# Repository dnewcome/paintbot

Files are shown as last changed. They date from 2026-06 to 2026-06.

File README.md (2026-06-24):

# paintbot

Hardware for a painting robot that mirrors an operator's brush movements in real
time (a live digital twin) and replays recorded stroke performances. A raked
**vertical CoreXY easel** (3×4 ft) carrying interchangeable, force-controlled tool
heads — a **voice-coil paint brush** and a **gel extruder** — prototyped first as
standalone heads on an existing ShopBot.

## Layout
- **[`docs/`](docs/README.md)** — design docs: architecture, motion sizing, belt
  resonance, the voice-coil actuator + brush head, and the extrusion head.
- **`cad/`** — parametric [build123d](https://github.com/gumyr/build123d) parts.
  Shared dimensions live in `cad/params.py` (and `cad/params_extruder.py`); each
  part file exports an STL and self-checks watertightness.

## Building the CAD
```bash
pip install build123d trimesh
python3 cad/<part>.py        # writes build/<part>.stl and prints a sanity line
```

Status, locked decisions, and open questions are tracked in
[`docs/README.md`](docs/README.md).

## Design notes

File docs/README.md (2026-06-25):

# Paintbot — Hardware Design Docs

Physical machine that mirrors the operator's painting movements in real time
(live digital twin) and replays recorded `TwinPerformance` op streams. A raked
vertical CoreXY easel carrying a multi-stage brush head.

## Documents
- **[hardware-architecture.md](hardware-architecture.md)** — top-level concept,
  governing design drivers, work envelope, axis map & drives, subsystems.
- **[motion-sizing.md](motion-sizing.md)** — CoreXY + coarse-Z sizing: torque
  budget, stepper (open-loop, 56 V, 30T pulley) vs FOC, counterbalance.
- **[belt-resonance.md](belt-resonance.md)** — the bandwidth cap at 3×4 ft:
  belt stiffness, tension nuance, frame modes, open-loop input shaping, measuring f_n.
- **[voice-coil-actuator.md](voice-coil-actuator.md)** — custom fine-Z brush
  stroke/pressure actuator: requirements, EM design point, Path B flexure, driver.
- **[voice-coil-head.md](voice-coil-head.md)** — brush tool head built/tested on
  the existing ShopBot first: mechanical stack-up, magnetic circuit, CAD parts.
- **[voice-coil-driver.md](voice-coil-driver.md)** — single-phase current-mode
  (=force-mode) driver + nested control loop + calibration; the bench-test path.
- **[extrusion-head.md](extrusion-head.md)** — second tool head: motor-driven
  syringe pump for thick gel medium (dip-and-load, single-bore reverse-fill, fat bead).
- **[planar-corexy.md](planar-corexy.md)** — construction variant: laser/waterjet
  plates locate the motion geometry, hybridized with the 8020 frame (after corexy.com R1).
- **[coarse-z.md](coarse-z.md)** — coarse-Z stage (full machine): belt-driven MGN12
  carriage presenting a 65 mm clamp; Z is horizontal in the easel (no self-lock).
- **[bom.md](bom.md)** — consolidated bill of materials: brush head, driver, planar frame.

## Decisions locked so far
- Raked vertical CoreXY easel, **3×4 ft** work area (which dim is vertical: TBD).
- Drives: **open-loop steppers** for XY initially (56 V, high-torque NEMA23
  ≥2.5–3 N·m, low-inductance, dual-shaft, 30T 2GT pulley); upgrade path to
  closed-loop. Reserve current/force control for the voice coil.
- **Two-stage Z:** coarse belt carriage (all gross lifts) + custom voice-coil
  fine-Z (Path B flexure, ~10 mm, current = force = brush line weight).
- **Interchangeable tool heads** sharing one ShopBot/Z-plate mount: (1) voice-coil
  brush (force-controlled, live feel); (2) gel extruder (volume-metered syringe
  pump, dip-and-load, single-bore reverse-fill, ~3 mm fat-bead nozzle).
- **Y counterbalanced with constant-force / gas spring, never a counterweight.**
- Bandwidth ceiling is **belt resonance**, not motor torque → 15 mm steel-core
  belt + ≥20 mm idlers + MGN12 rails + ~50–80 N tension + input shaping.

## Top open decisions
- [ ] Bed dimension assignment: which of 3 ft / 4 ft is vertical (Y)?
- [ ] Wrist single-DOF axis: lean vs. azimuth/roll.
- [ ] Voice coil detailed design (magnetic circuit + flexure) → build123d parts.

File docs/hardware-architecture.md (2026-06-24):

# Paintbot — Hardware Architecture

Physical realization of the paintbot software twin: a robot that mirrors the
operator's painting movements in real time (live digital twin) and can replay
recorded `TwinPerformance` op streams.

## Top-level concept

A **raked vertical CoreXY easel** carrying a multi-stage brush head. The operator
moves; the machine follows with minimal perceived lag, holding (for now) a paint
brush. Drives are robotics-grade BLDC servos under field-oriented control so the
head can be torque/impedance-controlled, not just position-commanded.

## Governing design drivers

1. **Latency is dominated by sensing/compute, not mechanics.** A well-tuned
   CoreXY tracks commands within single-digit ms. The mechanical goal is "don't
   be the bottleneck"; responsiveness is won with a predictive filter that
   extrapolates operator motion to mask camera latency.
   - Budget: **<50 ms end-to-end feels responsive, <20 ms feels truly live.**
2. **Moving mass vs. acceleration is the master tradeoff.** `a = F/m`. Every
   gram on the gantry (coarse Z, voice coil, wrist, brush) costs acceleration,
   and acceleration — not top speed — is what makes mirroring feel tight.
3. **Belt + frame stiffness set the control bandwidth.** The lowest mechanical
   resonance caps how aggressively the servo loop can be tuned. At ~1.2 m belt
   spans this is a real limit; favor wide steel-core belt, high tension, short
   free spans.

## Work envelope & orientation

| Parameter | Value |
|---|---|
| Canvas / bed | **3 × 4 ft** (~914 × 1219 mm) work area |
| Orientation | Vertical easel, **raked back ~10–20°** from plumb |
| X axis | Horizontal across canvas |
| Y axis | Vertical (gravity axis — counterbalanced) |
| Z coarse | Horizontal, brush standoff / relief depth |
| Z fine (voice coil)  | Horizontal, brush stroke + pressure |
| Wrist | 1 DOF (axis TBD — lean vs. azimuth/roll) |

### Why the rake
- Slight gravity bias holds brush toward canvas.
- Paint runs *down* the canvas, not *off* it.
- More stable base against the gantry's tipping moment.

## Axis map & drives

Platform: **moteus / ODrive-class BLDC under FOC**, daisy-chained on **CAN-FD**,
single real-time host (**Raspberry Pi + mjbots pi3hat** — real-time CAN-FD + IMU).

| Axis | Type | Driver | Notes |
|---|---|---|---|
| X | 3-phase BLDC | moteus (CAN-FD) | CoreXY motor A, frame-mounted |
| Y | 3-phase BLDC | moteus (CAN-FD) | CoreXY motor B, frame-mounted |
| Z coarse | 3-phase BLDC | moteus (CAN-FD) | Belt-driven carriage, NOT lead screw |
| Wrist tilt  | 3-phase gimbal | moteus / small FOC (CAN-FD) | Direct-drive, backlash-free, lightweight |
| **Z fine**  | **voice coil (1-phase)** | **dedicated current-mode H-bridge + encoder** | moteus CANNOT drive this — needs its own driver, host-synced |

**Key gotcha:** moteus/ODrive do FOC on *3-phase* motors. The voice coil is a
*single-phase* actuator, so it gets its own current-controlled driver. Payoff:
current control = force control = **brush pressure**, feeding straight into the
software's existing pressure channel.

## Motion subsystems

### XY — CoreXY
- Motors frame-mounted (only gantry + belts move).
- **Wide steel-core GT2/GT3 belt (9–15 mm).** Belt stiffness sets resonance.
- Direct-drive preferred to protect bandwidth; add small reduction only if
  torque comes up short (reduction adds reflected inertia, costs bandwidth).

### Y counterbalance — critical for a vertical machine
- Cancel the gantry's gravity load so Y motors don't burn continuous holding
  current (heat + stolen torque headroom).
- **Use a constant-force spring or gas spring — NEVER a counterweight.** A
  counterweight adds its mass to the inertia you must accelerate, roughly
  doubling effective Y moving mass and destroying acceleration.

### Z — two stages
- **Coarse:** lightweight belt-driven carriage (~100–300 mm), canvas standoff +
  relief depth. Slow path.
- **Fine:** custom voice coil (~10–30 mm stroke), brush stroke dynamics +
  pressure. High bandwidth, zero backlash, direct-drive.
  - Run in **current control → force → line weight.**
  - Mover hangs horizontally → side load. A dedicated linear guide carries the
    cantilever moment so the coil only pushes axially (coils dislike side loads
    on their own bearings). Keep brush + wrist short-coupled to carriage.

### Wrist — 1 DOF
- Lightweight gimbal-style BLDC, direct-drive, FOC.
- **Open sub-decision — which single axis:**
  - *Lean* (brush tips toward/away from canvas): brush loading/unloading; lean
    confined to one plane unless XY assists.
  - *Azimuth/roll* (spin brush about standoff axis): aligns a flat/chisel brush
    to stroke direction — better for calligraphic line-weight modulation, pairs
    well with pressure-controlled voice coil. **Current lean: azimuth/roll.**
- Consider remote-driving the wrist (belt/cable from gantry-mounted motor) to
  keep tip mass low — deferred.

## Performance targets (first pass)

| Quantity | Target |
|---|---|
| Motion to mimic | **Arm movements** (gross gesture) |
| Peak head velocity | ~2 m/s |
| Sustained acceleration | ~1 g (10 m/s²) |
| Peak acceleration | ~2 g (20 m/s²) |
| End-to-end latency | <50 ms (target <20 ms) |

### Rough moving-mass budget (to refine)
- X-carriage ≈ 1.5 kg (coarse-Z + VCA + wrist + brush + plate)
- Y (beam + carriage) ≈ 2.5–3 kg
- At 2 g peak + gravity counterbalanced → ~30–60 N at the belt →
  ~0.4–0.6 N·m at a 20T GT2 pulley. Upper edge of a single mj5208-class motor
  direct-drive → choose beefier BLDC or accept a small reduction.

## Deferred / later
- Physical paint reload: dip well + dip motion (software already models reload
  events). On a vertical canvas, well sits low/side.
- Motion scaling (1:1 vs. operator-small / canvas-large) — changes accel budget.
- Frame: stiff rectangular weldment/extrusion, raked, resisting tipping moment.

## Open decisions
- [ ] Bed dimension assignment: which of 3 ft / 4 ft is vertical (Y)?
- [ ] Wrist single-DOF axis: lean vs. azimuth/roll.
- [ ] Voice coil: off-the-shelf (Moticont/H2W/Akribis) vs. custom moving-magnet.
- [ ] XY motor exact part + direct-drive vs. reduction.

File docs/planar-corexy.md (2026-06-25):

# Planar-Plate CoreXY (hybrid with 8020)

A construction variant where **laser/waterjet planar plates locate the precise
motion geometry** and **8020 extrusion provides the large structural frame**.
Inspired by the [corexy.com Waterjet Aluminum R1](https://www.corexy.com/corexyr1/index.html).

## What the R1 teaches (borrow the philosophy, not the scale)
The R1 cuts a single 3/16″ aluminum sheet so that ONE plate locates both NEMA17s,
all 8 idlers, the drive pulleys, and the rail datums to waterjet tolerance — CoreXY
precision with no machined frame. Notable features:
- **Single-plane belt routing**, 8 idlers + 2 drive pulleys, all axes ⟂ to the
  plate, both belts coplanar (no stacked-belt cocking moment).
- Rails = 3/8″ precision shaft in epoxied bronze bushings.
- Tension by sliding the steppers in slots. Secondary parts laser-cut acrylic.

It is a **~12×14″ desktop** machine, though. The philosophy scales; the specifics
don't.

## What survives the jump to 3×4 ft vertical, and what doesn't
| R1 spec | Keep? | Paintbot choice (per earlier sizing) |
|---|---|---|
| Plate-locates-geometry | ✅ keep | the core idea — cut plates as precision jigs |
| Single-plane routing (8 idlers) | ✅ keep | pairs naturally with one plate plane |
| Motor-slot belt tensioning | ✅ keep | simple, effective |
| MXL 1/4″ belt | ❌ | **15 mm steel-core GT2/GT3** (forces + resonance) |
| 18T idlers | ❌ | **≥20 mm idlers** (steel-cord bend radius) |
| 3/8″ shaft + bronze bushing rails | ❌ | **MGN12 linear rails** (3/8″ shaft sags/whips at ~1.2 m) |
| 3/16″ single plate as whole frame | ❌ | **plates bolt to an 8020 perimeter**; thicker (¼–3/8″ Al) |

## Hybrid architecture
- **8020 perimeter frame** (raked vertical easel) = cheap, rigid bulk structure.
- **Planar plates bolt to the 8020**, carrying the *precise* motion geometry:
  - **2 top corner / motor plates** — NEMA mount + tension slots + corner idlers.
  - **2 bottom corner plates** — corner idlers + Y-rail lower ends.
  - **2 gantry-end plates (MOVING)** — MGN12 Y-carriage blocks + the gantry idlers
    + the X-rail mounts; these are the ends of the moving cross-beam.
  - **1 X-carriage plate** — MGN12 X-block + belt clamps + the shared tool-head /
    Z-plate interface (same mount the voice-coil + extruder heads bolt to).
- **Rails:** 2× MGN12 vertical (Y) on the uprights; 1× MGN12 horizontal (X) on the
  gantry beam. Plates carry the blocks / locate the rails.
- **Belt:** single-plane CoreXY, 15 mm steel-core, ≥20 mm idlers, motor-slot tension.

## Why this fits the paintbot
- Cheap precision for the fiddly belt/idler/rail geometry without machining.
- Plates are fast/cheap to iterate (re-cut a corner plate vs. re-machining).
- Marries to the big 8020 easel and keeps every stiffness decision already sized
  (steel-core belt, MGN12, counterbalance, input shaping).

## Plate ↔ 8020 marriage (to detail)
- Plates bolt to extrusion faces via T-nuts; locate against the extrusion edge or a
  pin for repeatability.
- Tool-head interface plate stays common across heads (voice-coil brush, extruder).

## Orientation: LANDSCAPE (4 ft wide × 3 ft tall)
| Axis | Span | Rail | Notes |
|---|---|---|---|
| X (horizontal, along gantry) | 4 ft / 1219 mm work | **MGN12 ~1370 mm on the moving gantry beam** | the long axis; carriage rides it |
| Y (vertical, gantry up/down) | 3 ft / 914 mm work | **2× MGN12 ~1120 mm on the uprights** | counterbalanced |
- **Motors: both at the BOTTOM corners** (weight low, wiring at the base).
- **Counterbalance:** constant-force springs pull the gantry up from the top beam.
- **Resonance note:** landscape makes the horizontal belt spans the longest
  (~1.4 m top/bottom) and the moving gantry beam the long member → keep the gantry
  beam stiff (boxed/carbon) and the belt 15 mm steel-core; this is the worst axis.

## Belt routing (single-plane, motors at bottom corners) — laid out
Reconstructed in `cad/routing.py` (emits `build/routing.svg`). Topology:
- **Belt A** (left motor): M_A → bottom edge → BR → up right upright → GR_a →
  along gantry → carriage → GL_a → down left upright → M_A.
- **Belt B** (right motor): M_B → bottom edge → BL → up left upright → GL_b →
  along gantry → carriage → GR_b → down right upright → M_B.
- The two bottom strands cross near center-bottom → **2 crossover idlers** stagger
  them (single-plane). **Top edge carries NO belt** → free for the counterbalance.
- **8 idlers:** BL, BR (bottom corners) + GL_a/GL_b/GR_a/GR_b (gantry ends) + 2
  crossover. Kinematics X=(a+b)/2, Y=(a−b)/2.
- Idler coordinates are first-pass — verify strand clearances against a reference build.

## Plate set status (laser DXF + STL fit-check)
| Plate | Carries | Status |
|---|---|---|
| `plate_xcarriage.py` | MGN12 X-block, belt clamps, tool interface | ✅ DXF |
| `plate_gantry_end.py` ×2 | MGN12 Y-block, gantry beam, 2 gantry idlers | ✅ DXF |
| `plate_motor_corner.py` ×2 | NEMA17 tension slots, bottom-corner idler, 8020 mount | ✅ DXF |
| `plate_crossover.py` | CX1/CX2 idlers (mid bottom), 8020 mount | ✅ DXF |
| (no top-corner plates) | top edge is belt-free | — |

Full-machine 3D view: `cad/assembly_corexy.py` → `build/assembly_corexy.png` — the
real flat plates at their routing positions + the **real brush head** on the carriage
reaching the canvas, with MGN12 rails / 8020 frame / NEMA23 motors as stand-ins, the
canvas slab, and the whole easel raked back. (Folds in the retired `machine.py` massing.)

## Open forks (need decisions before CAD)
- [ ] **Rails:** MGN12 linear (recommended — stiffness at 1.2 m) vs. R1-style
      shaft+bushing (cheaper/simpler plates, but compliant at this span).
- [ ] **Plate fab/material:** waterjet/laser **aluminum ¼–3/8″** (stiff, R1-like)
      vs. laser steel vs. acrylic/ply for a cheap first proto.
- [ ] **Routing:** single-plane (8 idlers, clean) vs. stacked-belt (fewer idlers,
      small cocking moment) — single-plane recommended to match the plate plane.
- [ ] Which of 3 ft / 4 ft is the vertical (Y) span (still open from architecture).

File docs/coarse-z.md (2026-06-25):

# Coarse-Z Stage (full machine)

The slow Z axis that sets canvas standoff + relief depth and does gross between-stroke
lifts. The fine voice-coil flexure only does ±5 mm, so coarse-Z covers everything
larger. **Only needed on the final machine** — on the prototype the Shapeoko/HDZ is
the coarse-Z. It rides the CoreXY X-carriage, so its motor mass is a moving-mass tax.

## Orientation insight (drives the whole design)
In the vertical easel, **Z (canvas normal) is HORIZONTAL**. Consequences:
- **Gravity is perpendicular to travel** → the motor never lifts the head against
  gravity → low holding torque, a **belt drive is fine** (no self-locking screw
  needed), and it can be back-drivable.
- The head weight becomes a **cantilever moment** on the Z rail (reacted by block
  spacing), not an axial load.

## Requirements
| Quantity | Value | Notes |
|---|---|---|
| Travel | ~100 mm | standoff (~20–50) + relief (~10) + gross lifts (~20–50) |
| Load | tool head ~0.5–0.8 kg, cantilevered ~100 mm | brush or extruder head |
| Cantilever moment | ~0.8 kg·9.81·0.1 ≈ 0.78 N·m | 2× MGN12 blocks handle easily |
| Speed | moderate (between-stroke lifts) | not on the fast/fidelity path |
| Motor mass | minimize (rides the gantry) | recurring constraint |

## Mechanism
- **Rail:** 1× **MGN12** along Z, **2 blocks spaced ~50 mm** to react the cantilever
  pitch moment (MGN12 block moment rating ≫ 0.78 N·m, so 2 blocks are ample).
- **Drive:** **2GT belt** loop along Z — light **NEMA17 pancake** (or NEMA14) at the
  gantry end, idler at the canvas end, carriage clamps the belt. Belt (not lead
  screw) per the project preference; gravity isn't along Z so no self-lock needed.
- **Tool interface:** the carriage presents a **65 mm clamp** (bore axis along Z) →
  the head's `body_collar` mounts the SAME way as on the Shapeoko HDZ. Use a **bought
  65 mm router/spindle clamp** (e.g. Carbide HD 65 mm mount or a generic OpenBuilds
  one) bolted to the carriage plate — no need to machine a clamp.
- **Fixed structure:** the Z rail mounts on a bracket that bolts to the CoreXY
  **X-carriage plate** and cantilevers toward the canvas; it also carries the motor
  (gantry end) and idler (canvas end).

## Parts
| Part | Fab | Status |
|---|---|---|
| `z_carriage.py` | laser plate: 2× MGN12 blocks + 65 mm-clamp mount + belt clamp | ✅ DXF |
| 65 mm router clamp | **bought** (Carbide HD / generic) | — |
| Z rail bracket (fixed) | laser/8020: rail mount + X-carriage join | ⏳ |
| Motor mount + idler | laser/printed | ⏳ |
| MGN12 rail + 2 blocks | bought | — |
| NEMA17 pancake + 2GT belt/pulley/idler | bought | — |

## Open
- Z rail bracket + X-carriage join (perpendicular plate join — tab/slot + angle).
- Motor/idler mounts + belt path.
- Confirm the bought 65 mm clamp's bolt pattern → set `ZC_CLAMP_*` in params_frame.
- Travel could grow if deep relief is wanted (rail length + belt scale linearly).

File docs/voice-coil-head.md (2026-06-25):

# Voice Coil Brush Head — Detailed Design & ShopBot Prototype

Self-contained brush-contact tool head: moving-coil VCA + double-parallelogram
flexure + paintbrush + position sensor, mounted as a tool on an existing
**ShopBot** (ShopBot = XY gantry + coarse-Z standoff; this head = fine-Z stroke +
pressure). Proves the entire contact/pressure system before the CoreXY frame exists.

## Prototype framing
- ShopBot provides XY paths (slow is fine) and coarse-Z standoff.
- This head provides fast fine-Z + **force/pressure control** (current = line weight).
- **Orientation caveat:** brush points DOWN → gravity acts ALONG the stroke axis
  (vs. horizontal in the final easel). Gravity is a constant bias in the force
  model `F = k_f·I − k_flex·x − mg`; calibrate it out, don't hard-code it.
- Validates: k_f, flexure spring rate & straightness, force/bandwidth, brush
  loading/lift behavior on real paint, the driver + control loop.

## Mechanical stack-up (top = ShopBot, bottom = canvas)
```
  [ ShopBot tool mount ]            ← interface plate (fit TBD)
  [ Stator housing ]                ← holds magnetic circuit; flexure ground
      back-plate / magnet / center pole / front-plate  → radial gap
  [ Flexure: compound (double) parallelogram ]
      ground clamps → 2 blade stages → moving carrier
  [ Moving carrier (axial) ]
      top: coil bobbin sits IN the gap
      bottom: brush holder
  [ Brush holder / quick-change ] → paintbrush
  [ Position sensor ] reads carrier (optional for v1 — force≈current)
```

## Magnetic circuit (moving coil, speaker-motor topology)
Radial-gap field so force constant `k_f = B·L·I` is ~position-independent over the
stroke (the reason for a proper gap vs. a nonlinear solenoid).

| Part | Material | First-cut dims |
|---|---|---|
| Center pole | 1018 steel, turned | Ø16 mm × (magnet+gap height) |
| Magnet | NdFeB N52 disc, axial | Ø25 × 10 mm (K&J-class) |
| Back plate | 1018 steel | Ø30 × 6 mm |
| Front plate | 1018 steel washer | OD30 / ID21 × 6 mm |
| Radial gap | — | ~2 mm (coil ~1 mm + ~0.5 mm clearance/side) |
| Coil | AWG26, ~160 turns | mean Ø~20 mm, k_f ≈ 5 N/A, R ≈ 1.3 Ω |

Expected gap B ~0.4–0.6 T → plenty (we're force-limited, not accel-limited; even
0.3 T works, just more current). Steel parts are simple turned cylinders/washers
(lathe or machine-shop / waterjet-stack); magnets bought; coil hand-wound; rest 3D-printed.

## Flexure — compound (double) parallelogram
- Two parallelogram stages with an intermediate carrier cancel the parasitic axial
  foreshortening of a single parallelogram → straight-line motion over ~10 mm.
- Blades: spring steel or BeCu shim, ~0.15–0.25 mm thick, clamped between printed
  spacers. Pick thickness so (a) spring rate is small vs. ~3–5 N working force and
  (b) blade stress < fatigue limit at full 10 mm deflection (infinite-life).
- Flexure also carries side load → coil only pushes axially; no separate rail.
- v1 simplification: a single parallelogram is acceptable (small parasitic, brush
  is compliant); compound is the target for clean position fidelity.

## Position sensor (optional for v1)
- Force ≈ current already, and flexure makes x↔force linear, so v1 can run
  current-mode force control with NO encoder.
- When wanted: AS5311 + 2 mm-pole magnetic strip on the carrier (~µm-class), or a
  cheap linear Hall (DRV5055) reading a carrier magnet (coarse but adequate).

## Driver (single-phase current-mode)
- H-bridge (DRV8874-class) + inline current sense (INA240), current PI loop
  @ 10–20 kHz on a Teensy/STM32; brush force = commanded current.
- Buy-path alt: Maxon ESCON in current/torque mode.

## BOM split
- **Bought:** NdFeB magnet, magnet wire (AWG26), shim stock (spring steel/BeCu),
  fasteners, H-bridge + current sense + MCU, (optional encoder).
- **Machined (simple, outsourceable):** 3 steel parts (pole, back plate, front plate).
- **3D-printed:** stator housing, coil bobbin, flexure spacers/clamps, brush
  holder/quick-change, sensor mount, ShopBot interface plate.
- **Hand-wound:** the coil.

## CAD (build123d) — `cad/`
Shared dims in `cad/params.py` (single source of truth). Cup opens DOWNWARD
(-Z toward canvas); magnet+pole at the back, coil rides the annular gap and
extends out the open mouth to the carrier + brush. Common attach interface:
**3× M3 on a 22 mm bolt circle** (bobbin foot ↔ carrier ↔ brush holder).

| File | Fab | Status |
|---|---|---|
| `pole.py` | lathe 1018 steel (Ø16×28 + register) | ✅ watertight |
| `steel_cup.py` | lathe 1018 steel (Ø32×46, opens down) | ✅ watertight |
| `bobbin.py` | printed flangeless former + foot (30 mm) | ✅ watertight (reworked) |
| `brush_holder.py` | printed, 8 mm ferrule pinch-clamp | ✅ watertight |
| `carrier.py` | printed: column + 2 blade clamp bars + attach flanges | ✅ watertight |
| `blade.py` | bought shim steel (t=0.1) — cut drawing, ×2 | ✅ watertight |
| `clamp_plate.py` | printed blade sandwich plate, ×4 | ✅ watertight |
| `body_collar.py` | printed: **Ø65 Shapeoko HDZ collar** + cup holder | ✅ watertight |
| `flexure_ground.py` | printed U-frame: holds blade ends + bridges to collar | ✅ watertight (manifold) |
| `assembly_brush.py` | full-stack viz + z-stack/clearance check | ✅ renders, clearances OK |

**Mount:** the head drops into the Shapeoko **HDZ 65 mm router clamp** — `body_collar`
IS the 65 mm collar, no bolt pattern needed. **Head width ~168 mm** (set by the soft
long-blade flexure); a folded flexure could compact it later if needed.

### Flexure spring rate (validated)
Symmetric 2-blade (4 guided-cantilever segments): `k = 4·E·w·t³/a³`. With spring
steel t=0.1, w=20, a=34 → **k ≈ 0.41 N/mm**; stress at 5 mm ≈ 260 MPa (infinite
life). Measured-from-CAD **mover mass ≈ 37 g** → gravity sag **0.9 mm**, accel
headroom ~55 g, suspension resonance ~17 Hz (extend via closed loop; tune k by
swapping blade-shim thickness, k ∝ t³).

### Z-stack & remaining geometry (next)
Cup opens down; magnet+pole at the back; **pole lengthened to 28 mm** so the coil
stays in the radial gap over ±5 mm travel; carrier bore opened to Ø18 to clear the
pole tip; shared attach interface widened to **3× M3 @ 26 mm BC, Ø32 flanges**.
- **bobbin reworked ✅:** flangeless 30 mm former — coil epoxies onto the upper
  16 mm (riding the gap near the mouth), thin top lip Ø21.5 clears the Ø22.5 bore,
  Ø32 foot sits below the mouth and bolts to the carrier. (Winding retainer flanges
  were dropped — Ø24 flange would foul the Ø22.5 cup bore; real voice coils are
  flangeless anyway.)
- **main_body:** waits on the real ShopBot Z-plate bolt pattern.

## Fit unknowns blocking CAD (need from operator)
- [ ] ShopBot tool-mount interface (spindle/router diameter to clamp, or Z-plate bolt pattern).
- [ ] Paintbrush: ferrule diameter + brush type (round/flat) for the holder.
- [ ] Steel-part fab: in-house lathe/mill vs. order-out (no-machining alt designs).
- [ ] 3D printer material + build volume (PETG/ABS/nylon; housing size).

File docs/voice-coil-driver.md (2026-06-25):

# Voice Coil Driver + Control Loop

Single-phase, bidirectional, **current-mode (= force-mode)** driver for the brush
voice coil. This is the electronics/firmware that makes the head testable: the
flexure gives ~zero friction, so `F ≈ k_f·I` holds and **commanded current is brush
force** — line weight straight out of the current loop.

## Requirements (from the actuator sizing)
| Quantity | Value | Source |
|---|---|---|
| Coil resistance R | ~1.3 Ω | `docs/voice-coil-actuator.md` |
| Coil inductance L | ~0.5–2 mH (measure) | est. (160 T, steel-cored gap) |
| Force constant k_f | ~3.3–4.2 N/A | depends on built gap B (0.35–0.45 T) |
| Peak force / current | 20 N → ~5–6 A (burst) | fast dabs |
| Continuous force / current | 3–5 N → ~1.2–1.5 A | brush pressure |
| Current-loop bandwidth | ~1–2 kHz | well above the ~17 Hz suspension mode |
| Force/pressure update | ~1 kHz from host | live mirroring |

## Topology
```
  24V ──┬─[bulk cap]─┐
        │            │
        │      ┌───H-bridge───┐        ┌──── voice coil ────┐
   MCU ─┼─PWM─▶│ DRV8874-class│──OUT1──┤  (single coil)     │
        │      │ (IN1/IN2 PWM)│──OUT2──┤                    │
        │      └──────┬───────┘        └────────┬───────────┘
        │             │  inline shunt 10 mΩ ────┘
        │        INA240 (×50, bidirectional) ──▶ MCU ADC (signed I)
        │
        └─ host link: USB-serial or CAN-FD ◀── pressure/position setpoints
   (optional) AS5311 linear encoder on carrier ──▶ MCU (position x)
```
- **Power stage:** full H-bridge, **DRV8874-class** (4.5–37 V, ~6 A peak, ~3 A cont).
  Covers bursts to ~20 N; if sustained 20 N is ever needed, step up to DRV8701 +
  external MOSFETs or a DRV8412. Supply **24 V** for current-slew headroom
  (di/dt = V/L ≈ 24 A/ms at 1 mH → reaches 5 A in ~0.2 ms).
- **Drive mode:** IN1/IN2 PWM (NOT the driver's internal current chopper) so the
  **MCU closes the current loop** — needed for clean bidirectional force control.
  ~20–40 kHz PWM, with deadtime.
- **Current sense:** inline 10 mΩ shunt + **INA240** (PWM-rejecting, bidirectional,
  gain ×50): 5 A → 50 mV → 2.5 V about a Vref/2 bias → MCU ADC. Sample
  **synchronized to PWM center** to reject ripple.
- **MCU:** **STM32G4** (motor-control timers + fast ADC + CORDIC) for the real
  thing; **Teensy 4** for a fast first proto. Current loop in the PWM ISR (20 kHz).

## Control architecture (nested)
```
 host pressure setpoint ─▶ [force model] ─▶ I_cmd ─▶ [PI current loop @20kHz] ─▶ PWM
                              ▲                          ▲
              x (if encoder) ─┘            sensed I (INA240, synchronous) ┘
```
- **Inner: PI current loop** (the only fast loop). Plant = R + sL. Pole-zero
  cancel: `Kp = L·ω_bw`, `Ki = R·ω_bw`, ω_bw = 2π·1.5 kHz. With L≈1 mH, R≈1.3 Ω →
  Kp ≈ 9.4 V/A, Ki ≈ 1.2e4 V/A/s (starting points; tune on the bench).
- **Force model** (feedforward, converts desired brush force to coil current):
  `I_cmd = (F_brush + k_flex·x − m·g·ĝ) / k_f`
  - `k_flex·x` — flexure spring (needs x; if no encoder, fold the near-constant
    contact-region term into calibration).
  - `m·g·ĝ` — gravity bias; `ĝ = +1` on the ShopBot (brush DOWN, gravity along the
    stroke) vs ~0 on the final vertical easel. **Don't hard-code — it's a parameter.**
- **Outer loop (optional v1):** with an AS5311 encoder, a position PID can do clean
  lift/standoff moves (output = I_cmd); without it, the ShopBot's coarse-Z does
  lifts and this head runs pure force control.

## Calibration (bench, one-time + per-build)
1. **k_f:** clamp the head over a scale, command stepped currents, fit force vs I.
2. **k_flex:** push the carrier known deflections, read force on the scale (≈0.41 N/mm).
3. **Gravity offset:** at zero current, read the rest force (orientation-dependent).
4. **Coil R, L:** LCR meter (sets the current-loop gains).
Assemble into the force model; verify a commanded force matches a measured force.

## Protection / safety
- Driver overcurrent + thermal (built-in); firmware **continuous-current limit**
  (~2 A) to protect the coil thermally (I²R ≈ few W).
- **Host-timeout watchdog:** if setpoints stop streaming, ramp force to zero (and
  let coarse-Z lift) — never leave the coil energized into the canvas.
- Bulk cap + body-diode freewheeling for the inductive load; deadtime to avoid
  shoot-through.

## Host interface
- **Prototype:** PC streams pressure setpoints over USB-serial (or CAN) at ~1 kHz;
  MCU runs the 20 kHz current loop. USB latency ~1 ms — negligible vs. the loop.
- **Final machine:** this MCU joins the **CAN-FD** bus with the moteus axes, taking
  synchronized setpoints from the pi3hat host (single real-time timeline).

## BOM (driver board)
- DRV8874 (or DRV8412 / DRV8701+MOSFETs for more headroom)
- INA240A2 + 10 mΩ ≥1 W shunt
- STM32G474 (or Teensy 4.0)
- 24 V supply, bulk cap (≥470 µF low-ESR), gate/decoupling caps
- CAN-FD transceiver (final) or USB (proto)
- optional: AS5311 + 2 mm-pole magnetic strip (position)

## Next
- KiCad schematic + board (fits the project's existing ngspice→pcbnew→build123d
  toolchain) — deferred until the topology is bench-confirmed on a dev board.

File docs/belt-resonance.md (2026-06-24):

# Belt Resonance — the bandwidth cap at 3×4 ft

At this scale the binding constraint on responsiveness is **not motor torque** — it's
the first mechanical resonance of the long CoreXY belt loops. The belt is a spring;
the carriage mass on that spring resonates at
`f_n = (1/2π)·√(k_eff/m)`, and you can only push the motion bandwidth to roughly
**f_n / 3** before you start exciting ringing. Estimated baseline ~20–30 Hz →
usable bandwidth ~7–10 Hz. Goal: push f_n up, and use feedforward shaping to get
effective bandwidth above arm-gesture content (<5–8 Hz) with margin.

## The levers (in order of leverage)

### 1. Belt tensile stiffness — `k ∝ E·A` (biggest mechanical lever)
- Axial (longitudinal) stiffness of a span = `E·A / L` — set by **cord modulus ×
  cross-section**, NOT by tension (see tension note).
- **Steel cord (E ≈ 200 GPa) ≫ fiberglass (≈ 70 GPa) ≫ polyester.**
- Width: 15 mm ≈ 2.5× the section of 6 mm.
- Combined **15 mm steel-core vs 6 mm glass-core ≈ 3–7× stiffer** → f_n up √(3–7)
  ≈ **1.7–2.7×** → roughly **40–55 Hz**, lifting usable bandwidth ~7→~15 Hz.
  This single change roughly doubles your responsiveness ceiling. Non-negotiable.
- Cost of steel cord: a **minimum bend radius** → idlers must be larger (≥ ~20 mm
  toothed; avoid 16 mm/625-class idlers) or the cord fatigues.

### 2. Free-span length — `k ∝ 1/L`
- Shorten the unsupported belt run between the carriage and the nearest pulley.
- Can't beat CoreXY topology, but place motors/idlers to keep carriage-to-pulley
  runs short; add an idler to break the single longest span if needed.

### 3. Moving mass — `f_n ∝ 1/√m`
- Halving moving mass raises f_n by 41%. Every gram on the head helps here too —
  reinforces the light coarse-Z motor and a light (carbon/boxed) gantry beam.

### 4. Belt tension — a nuance, NOT a stiffness knob
- Tension does **not** meaningfully raise *axial* cord stiffness.
- It matters for two other reasons:
  - Keeps the **slack side from going slack** under peak accel force (slack side
    going loose = lost stiffness + backlash). Peak carriage force ~70 N → slack
    side stays taut if preload `T > F/2 ≈ 35 N`; use **~50–80 N/belt** for margin.
  - Raises the **transverse "guitar-string" mode** of long spans (stops them
    singing). That mode rises with tension; axial stretch does not.
- Don't over-tension beyond this — no stiffness gain, just bearing load + fatigue.

## Compliance the belt formula ignores — frame & gantry modes
- **Use linear rails (MGN12), not V-wheels** — wheels are a major compliance source.
- **Rigid gantry beam** (carbon tube or boxed extrusion): a flexing/twisting beam
  is its own low mode.
- **Anti-rack:** CoreXY can twist the gantry out of square because the two belt
  forces act at separated points. Keep the beam torsionally stiff and the bearing
  spacing wide.

## Control-side — works WITH open-loop steppers
- **Input shaping (ZV / ZVD / EI shaper) on the commanded trajectory is
  feedforward** → it works open-loop (this is exactly how fast CoreXY printers hit
  high accel without ringing). Tune the shaper to the measured f_n.
- This is the cheapest, highest-leverage single move. It raises *effective*
  bandwidth without changing the mechanics.

## MEASURE, don't guess
- Mount an **accelerometer (ADXL345)** on the carriage; impulse/sweep test to read
  the actual resonance peak(s) (Klipper-style resonance measurement, or a quick
  belt-twang FFT). Design the input shaper around the measured peak.
- Re-measure after the steel-core belt + rail upgrades to confirm the new f_n.

## Recommended config & actions
- Belt: **Gates 2GT/3GT, 15 mm, STEEL core.**
- Idlers: **≥ 20 mm toothed** (steel cord bend-radius limit); minimize longest span.
- Tension: **~50–80 N/belt**, set by twang frequency or a tension gauge.
- Guides: **MGN12 rails**; rigid carbon/boxed gantry beam; wide bearing spacing.
- Control: **input shaper tuned to measured f_n**; instrument with ADXL345 first.
- Order of operations: build → measure f_n → steel belt + rails → re-measure →
  tune input shaper to the final peak.

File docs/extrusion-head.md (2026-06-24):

# Gel Extrusion Head — Motor-Driven Syringe (Dip-and-Load)

A second interchangeable tool head for the paintbot: a **positive-displacement
syringe pump** that draws thick gel-viscosity medium from a well and deposits it
as fat impasto beads. Mounts on the existing **ShopBot** like the brush head, and
later on the CoreXY frame. Complementary to — not a replacement for — the
voice-coil brush.

## Where it fits vs. the brush head
| | Voice-coil brush | Gel extruder (this) |
|---|---|---|
| Control variable | **Force** (current = line weight) | **Volume** (steps = mm³ deposited) |
| Bandwidth | high (live feel, <20 ms) | low — feedforward metering, fights ooze |
| Digital-twin role | live-feel strokes | deliberate material deposition |
| Loading | dip brush in paint | **dip nozzle, reverse-draw a charge** |

**Key mindset:** the extruder is NOT a high-bandwidth head. Thick paint is
compliant and slow to relax, so you command volume open-loop-ish with feedforward
(linear-advance-style lead) and rely on **retraction** to stop ooze at stroke end —
exactly like a 3D-printer paste extruder. Don't expect brush-like responsiveness.

## Locked decisions (2026-06-24)
- **Topology:** leadscrew-driven syringe plunger (positive displacement). Only
  topology that both *draws* (reverse) and *retracts* cleanly. Pneumatic rejected
  (air compressibility = mush + lag); progressive-cavity rejected (can't refill).
- **Refill:** **single-bore reverse-fill** — dip one moderate nozzle deep in a
  well, reverse the motor to draw a charge. No valves. (Fat-bead nozzle is large
  enough to draw through; the valve/selector complexity isn't justified.)
- **Medium / nozzle:** **heavy gel, fat bead → ~3 mm nozzle.** Low pressure, very
  forgiving. This is the easy corner of the design space.
- Mounts as a ShopBot tool head; reuses the common ShopBot interface plate.

## Sizing — why a small bore
Plunger force = nozzle pressure × plunger area. Smaller bore = less force, finer
volume resolution. Heavy gel through a fat 3 mm nozzle is low pressure (~2–4 bar):

| Syringe | Plunger ID | Area | Force @ 4 bar |
|---|---|---|---|
| 30 cc | 21.7 mm | 370 mm² | ~150 N |
| **10 cc** | **14.5 mm** | **165 mm²** | **~66 N** |

**Decision: 10 cc Luer-lock barrel.** ~66 N working force is trivial for a NEMA17 +
leadscrew. Even the 10-bar worst case (~165 N) is in reach, so there's huge margin.

### Drive train
- **NEMA17** + flexible coupling → **T8 leadscrew, 8 mm lead** (2 mm pitch ×
  4-start) with anti-backlash brass nut.
  - Force: `F = 2π·τ·η/lead ≈ 2π·0.4·0.3/0.008 ≈ 94 N` continuous — covers the
    66 N case with margin. (Drop to **2 mm lead** for ~370 N + 4× resolution if a
    finer nozzle / stiffer medium is ever wanted; costs 4× speed.)
  - 8 mm lead chosen for **retraction speed** — fast retract is what kills ooze.
  - Resolution: 8 mm × 165 mm² = 1320 mm³/rev ÷ (200 × 16 µsteps) ≈ **0.4 mm³/µstep.**
- **2× Ø8 guide rods** flank the screw → carriage can't rotate (no anti-rotation
  feature needed on the nut) and takes the plunger side load.

### Refill (draw) is flow-limited, not force-limited
Drawing gel in is capped by atmospheric pressure pushing it through the nozzle
(~1 bar over 165 mm² ≈ 16 N — nothing). The real limit is **cavitation / air
ingress** if you draw faster than gel flows through the nozzle. So: **draw slowly,
nozzle fully submerged in a deep well**, then a small forward purge to clear the
tip before painting.

## Mechanical architecture (top = ShopBot, bottom = canvas)
```
  [ ShopBot interface plate ]          ← shared with brush head (bolt pattern TBD)
  [ Motor top plate ]  NEMA17 + flex coupling
  [ Leadscrew (T8x8) + 2x Ø8 guide rods ]
  [ Plunger carriage ]                 ← brass nut + 2 linear bearings;
       C-slot CAPTURES the plunger thumb-rest  → pushes AND pulls (mandatory for draw)
  [ Syringe barrel ]  10 cc Luer-lock, held in a bottom cradle (keyhole grips finger flange)
  [ Luer nozzle ]  ~3 mm conical, printed/metal
```
**Critical detail:** the carriage must *capture* the plunger flange (a C-slot the
thumb-rest slides into), not just bear on it — otherwise reverse can't draw.

## Control / calibration
- **e-steps:** calibrate mm³/step by weighing dispensed mass (density known).
- **Retraction:** tune retract distance + speed empirically to stop ooze at stroke
  end (start ~1–3 mm of plunger travel).
- **Linear advance:** lead the extrude command vs. XY motion to mask the
  compliance/ooze lag of thick medium.
- **Driver:** same stepper driver family as the rest of the machine (open-loop
  fine; volume errors are forgiving and re-primed each load cycle).

## Dip-and-load cycle
1. Park over a **deep** paint well; lower until nozzle is fully submerged.
2. Slow reverse → draw a charge (rate-limited to avoid air ingress).
3. Small forward purge to prime the tip / expel any drawn air.
4. Move to canvas; deposit beads with linear-advance lead; retract at stroke end.
5. Re-load when the charge runs low (10 cc = many fat strokes).

## BOM split
- **Bought:** 10 cc Luer-lock syringes, T8×8 leadscrew + anti-backlash nut, flex
  coupling, 2× Ø8 hardened rod + linear bearings (LM8UU), NEMA17, fasteners,
  Luer nozzles/tips.
- **3D-printed:** motor top plate, plunger carriage (flange-capture C-slot),
  syringe cradle, nozzle (or use metal Luer tip), ShopBot interface plate (shared).
- **Machined:** none required (all-printed structure; this head is low-force).

## CAD (build123d) — `cad/`
Separate param file `cad/params_extruder.py` (imports the shared ShopBot interface
+ fastener constants from `params.py`). Stroke axis = Z, plunger pushes −Z (down).

| File | Fab | Status |
|---|---|---|
| `params_extruder.py` | shared dims | ✅ done |
| `ext_top_plate.py` | printed: NEMA17 + coupling + rod seats (68×60×8) | ✅ watertight |
| `ext_carriage.py` | printed: nut pocket + 2× LM8UU + plunger C-slot (68×52×26) | ✅ watertight |
| `ext_cradle.py` | printed: barrel channel + finger-flange capture (68×44×18) | ✅ watertight |
| `ext_nozzle.py` | printed Luer ~3 mm cone (12×12×20) | ✅ watertight |
| interface plate | shared with brush head (bolt pattern TBD) | ⏳ blocked on real Z-plate pattern |

**Layout note:** envelope is **68 mm wide** — Ø15 LM8UU bearings on 45 mm rod
spacing won't fit a narrower block. Syringe axis is offset **30 mm** in front (−Y)
of the leadscrew (coaxial would collide screw tip ↔ plunger). Both the carriage
plunger capture and the cradle flange capture are front-loading C-slots that trap
their disc/flange in Z (push *and* pull), so the syringe drops in from the front.

## Fit unknowns blocking CAD (need from operator)
- [ ] ShopBot Z-plate bolt pattern (shared with brush head).
- [ ] Confirm syringe brand/size → exact barrel OD, finger-flange + thumb-rest dims
      (10 cc varies between brands; cradle + C-slot key off these).
- [ ] NEMA17 length / pancake vs. standard (affects top-plate stack height).

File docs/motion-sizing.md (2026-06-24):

# Motion Sizing — CoreXY + Coarse-Z (3×4 ft vertical easel)

First-pass sizing. Masses are estimates to refine once parts are real. Frame size
is 3×4 ft (~914×1219 mm work area); which dim is vertical (Y) is still open but
doesn't change motor torque (only belt length / resonance).

## Moving-mass budget (estimate)
| Item | Mass |
|---|---|
| X-carriage (coarse-Z + voice coil + wrist + brush + plate) | ~1.5 kg |
| Cross-beam (X span, stiff but light extrusion or carbon tube) | ~1.0–2.0 kg |
| **Y moving mass** (beam + carriage) | **~2.5–3.5 kg** |
Note: the coarse-Z **motor rides the X-carriage**, so its mass is in BOTH the X and
Y moving totals → keep the Z motor light (it's a real accel tax, unlike the
frame-mounted XY motors).

## Acceleration target
- Mimic **arm gestures**: ~2 m/s peak, **~1 g sustained (10 m/s²), ~2 g peak (20 m/s²)**.

## CoreXY torque budget
Pulley: 20T 2GT, pitch dia 12.73 mm → r = 6.37 mm. Travel = 40 mm/rev.
CoreXY force→torque mapping (per motor): pure-axis move τ = F·r/2; worst-case
diagonal τ = (|Fx|+|Fy|)·r/2.

| Move | Head force (gravity counterbalanced) | Per-motor torque |
|---|---|---|
| Pure X, 2 g (1.5 kg) | 30 N | 0.10 N·m |
| Pure Y, 2 g (3.5 kg) | 70 N | 0.22 N·m |
| Worst diagonal, 2 g | Fx 30 + Fy 70 | **0.32 N·m** |
| + friction/preload + 1.5× margin | | **~0.5 N·m peak / motor** |

**Continuous** torque is far lower (accel is transient; cruise = just friction).
Speed: 2 m/s with 40 mm/rev = 50 rev/s = **3000 rpm** (10 kHz full-step rate).

### These motors are FRAME-MOUNTED → mass doesn't matter
Unlike the head, XY motor mass is free (no accel penalty). So we can use a beefy
motor purely for torque/stiffness.

## Motor options for XY

### Option 1 — moteus/ODrive BLDC (FOC), per original plan
- mj5208-class: ~0.3 N·m continuous, ~1.7 N·m peak → covers 0.5 N·m peak easily.
- Gains: closed-loop (never loses position under aggressive mirroring), torque/
  impedance control, deterministic CAN-FD, clean low-latency setpoint streaming.

### Option 2 — STEPPERS on existing 4.5 A drivers  ← user has these
- 0.5 N·m peak @ 3000 rpm is reachable with a **high-torque NEMA23** (≥1.9 N·m
  holding) **on a high-voltage bus (48–60 V)**. Voltage is the lever for stepper
  speed: torque falls with rpm (back-EMF + winding inductance); a high bus
  voltage + low-inductance ("high-speed" wound) motor keeps torque up at 3000 rpm.
- 4.5 A drivers are plenty of current; make sure they're rated for / fed a high
  voltage. A 3 N·m holding NEMA23 at 48 V should still deliver ≥0.5 N·m near
  3000 rpm — adequate, but verify against the motor's torque-speed curve.
- **What steppers give up vs FOC:**
  1. *Open-loop* steppers can **lose steps** on the unpredictable hard reversals
     of live human mirroring → twin drifts. Fix: **closed-loop steppers**
     (stepper + encoder, e.g. integrated "iHSS"/CL drivers) — recovers position
     robustness. Strongly recommended if going stepper.
  2. **No torque/force control** — can't "feel" the canvas or be back-driven.
     BUT: the *feel* requirement lives at the **brush contact = voice coil**, not
     at XY. XY only needs to track position fast. So steppers for XY is well
     justified; keep current/force control only where it matters (voice coil,
     maybe wrist).
  3. Mid-band resonance — handled with microstepping + input shaping.

### Decision: OPEN-LOOP steppers initially (upgrade path to closed-loop)
Open-loop costs nothing on latency (step/dir is low-latency) — it only risks
**position integrity**, not responsiveness. Viable here because:
- ~4× torque margin (3 N·m motor vs ~0.72 N·m demand) IS the "poor man's closed
  loop" — keeps steps from being lost. So do NOT tune accel to the edge; keep
  commanded accel well under available torque at speed (open-loop can't recover).
- Paint is forgiving: sub-mm XY drift is visually invisible on a painting (unlike
  a 3D print) → lost steps are a soft failure.

Open-loop guardrails:
- **Home between strokes/sessions** (limit switches) to re-register against silent
  drift.
- **Mid-band resonance** (~5–15 rev/s) is stall-prone → microstep 16+, use 56 V to
  pass through quickly, don't dwell cruise speeds there.
- **Step-rate ceiling:** 30T @ 2000 rpm × 16 µstep ≈ **107 kHz/axis** — confirm the
  pulse generator (Teensy/STM32 OK) handles it while streaming live setpoints.
- **Buy dual-shaft (rear-shaft) NEMA23 now** → adding an encoder for closed-loop
  later is a bolt-on, no motor swap.

### Sizing recommendation
Run XY on the 4.5 A drivers at the full **56 V** + high-torque **NEMA23
(≥2.5–3 N·m, low-inductance, dual-shaft) + 30T 2GT pulley** (~2000 rpm @ 2 m/s,
comfortable torque margin). Reserve FOC current-control for the voice coil (and
optionally wrist).
Caveat on control firmware: live teleoperation needs **streamed setpoints at low
latency**, not a G-code look-ahead planner — Klipper is great for steppers but is
built around G-code planning; for live mirroring use a streaming-capable real-time
step generator (Teensy/STM32 from host setpoints) or closed-loop drivers fed by it.

## Coarse-Z sizing
- Horizontal travel ~150–250 mm; carries fine head ~0.5–0.8 kg; belt-driven (not
  screw, per preference). No gravity along travel; head cantilevers → side load on
  a MGN9/12 rail.
- Needs moderate speed (it now does ALL gross lifts since the flexure voice coil
  is only ~10 mm). 1 g on 0.8 kg = 8 N → trivial torque. **Use a LIGHT motor**
  (small NEMA17 closed-loop or compact BLDC) because it rides the gantry.

## Y counterbalance
- Gravity load = Y mass × g ≈ 3.5 × 9.81 ≈ **34 N**.
- Use **constant-force spring(s)** (~34 N total, ideally a pair for symmetry) or a
  ~30–40 N gas spring. NEVER a counterweight (adds inertia, kills accel).

## ⚠ Top risk at this scale: belt resonance, not motor torque
CoreXY's long diagonal belt routing makes belt stretch the dominant compliance at
~1.2 m spans. Rough first-mode estimate:
- Steel-core 9–15 mm belt, span ~1.2 m → effective k ~ 30–60 N/mm.
- f_n = (1/2π)·√(k/m), m ≈ 1.5 kg → **~20–30 Hz first resonance.**
- That caps usable servo bandwidth to ~1/3 of f_n ≈ **7–10 Hz** (with a notch).
- Arm-gesture content is mostly < 5 Hz → workable, but it's THE binding constraint.

Mitigations (do all): **15 mm steel-core GT3 belt** (not optional at this size),
high tension, minimize moving mass (f_n ∝ 1/√m), short free spans via idler
layout. Fallback if CoreXY proves too compliant: **dual-drive gantry** (independent
motor per side on the long axis) keeps belts short/stiff at the cost of one motor
riding the gantry.

## Recommended starting parts
- Belt: Gates 2GT/3GT, **15 mm, steel-core**; 20T pulleys; ≥16 mm toothed idlers.
- XY motors: high-torque NEMA23 (≥1.9 N·m) on 48–60 V + the 4.5 A drivers
  (closed-loop preferred) — OR moteus mj5208 ×2 if going FOC.
- Guides: MGN12 (Y verticals + X beam) for stiffness at this size.
- Coarse-Z: light NEMA17 closed-loop / small BLDC + 2GT belt + MGN9/12, ~200 mm.
- Counterbalance: constant-force spring pair (~34 N) or 30–40 N gas spring.

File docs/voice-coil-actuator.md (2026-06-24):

# Fine-Z Voice Coil Actuator — Spec

Custom voice coil actuator (VCA) for the brush stroke + pressure axis. Built
in-house: materials ~$30–80 + encoder ~$20–40 vs. ~$300–700 off-the-shelf
(Moticont/H2W). Electromagnetics are easy here; the engineering is mechanical
(guide, encoder, force linearity, thermal).

## Role in the system
- **Fine-Z only.** Contact dynamics: pressure modulation + quick in-stroke lifts.
- Gross lift / canvas standoff / relief depth = **coarse-Z** (separate belt stage).
- Axis is **horizontal** → no gravity load along the stroke. Continuous force is
  just brush-contact pressure (small). Side load (gravity on the mover) is taken
  by the guide, NOT the coil bearings.
- Current control → force → **brush line weight**, into the software pressure channel.

## Requirements

| Spec | Target | Notes |
|---|---|---|
| Stroke | ~20 mm (Path A) / ~8–10 mm (Path B) | See guide fork below |
| Continuous force | ~3–5 N | Brush pressure only (no gravity to fight) |
| Peak force | ~20 N | Snappy dabs/stipple + headroom |
| Small-signal BW | 30–100 Hz | Pressure response, brush detail |
| Mover mass | <60 g | Coil + bobbin + brush holder + brush |
| Position feedback | linear encoder | e.g. AS5311 + magnetic strip |
| Force feedback | current (v1); load cell (optional v2) | Current = open-loop force |

## Electromagnetic design point (moving coil, cylindrical)

Loudspeaker-style motor: center NdFeB magnet + steel return cup; coil rides the
annular gap. `F = B·L·I = k_f·I`.

| Parameter | Value |
|---|---|
| Gap flux B | ~0.5 T (N52 + steel return) |
| Coil mean dia | 20 mm |
| Turns N | ~160 (AWG26) |
| Force constant | k_f ≈ 5 N/A  |
| Coil resistance  | R ≈ 1.3 Ω |
| Copper mass | ~12 g |
| 20 N peak | 4 A → ~21 W burst (fine) |
| 5 N continuous | 1 A → ~1.3 W (trivial) |
| Mover ~60 g | peak accel ≈ 330 m/s² (~34 g) |

**Conclusion: force/pressure-limited, NOT acceleration-limited.** Huge accel
headroom → optimize the design for pressure fidelity, not power.

## Topology choice: moving-coil vs moving-magnet
- **Moving-coil (chosen v1):** lightest mover, simplest magnetics (one magnet
  stack + steel cup + wound bobbin), best bandwidth. Cost: flexing lead wires
  (manageable over ~20 mm with strain relief / short drag loop).
- **Moving-magnet:** coil + wires stationary (no flex, more rugged) but heavier
  mover. Revisit if lead-wire fatigue becomes a problem.

## Guide: Path B — flexure, ~8–10 mm (CHOSEN)
Parallel leaf-spring (double-parallelogram) flexure: zero friction / stiction /
backlash → best brush pressure / line-weight fidelity, which is the expressive
core. Coarse-Z handles ALL gross lifts (so coarse-Z must be reasonably quick for
between-stroke lifts and stipple > ~10 mm). The flexure adds a known linear
spring rate that gets calibrated out of the force model (F = k_f·I − k_flex·x).

Design notes for the flexure:
- Double-parallelogram (compound) flexure keeps motion straight (no arc/parasitic
  tip) over ~10 mm — important so the brush tracks a true line into the canvas.
- Pick blade material/thickness so spring rate is small vs. the ~3–5 N working
  force (e.g. spring-steel or BeCu blades), and so blade stress stays well under
  fatigue limit at full 10 mm deflection (infinite-life design).
- Flexure also provides the side-load stiffness, so the coil only pushes axially —
  no separate linear rail needed. This is the elegance of Path B.

(Rejected Path A: ~20 mm linear rail — faster big in-stroke lifts, but rail
friction corrupts open-loop force fidelity.)

## Driver (single-phase — moteus CANNOT drive this)
- H-bridge current-mode loop, NOT a 3-phase FOC controller.
- DIY path: STM32/Teensy + DRV8874-class H-bridge + inline current sense
  (INA240), current PI loop @ 10–20 kHz; AS5311 linear encoder for position;
  outer position/force loop on the host or MCU. Host-synced over the same
  real-time fabric as the CAN-FD axes.
- Buy path: Maxon ESCON / AMC analog servo drive in current/torque mode (~$150+).

## Build risks to watch
- Force linearity over stroke (coil overhang vs magnet underhang geometry).
- Guide friction corrupting force control (→ Path B flexure removes this).
- Lead-wire fatigue (moving-coil) — strain relief / consider moving-magnet.
- Coil thermal at sustained high force (low for our few-N continuous need).

## Open
- [ ] Guide fork: Path A (rail, 20 mm) vs Path B (flexure, ~10 mm).
- [ ] Brush holder / quick-change interface + brush mass measurement.
- [ ] Encoder choice + mounting datum.

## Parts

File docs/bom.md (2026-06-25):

# Bill of Materials (consolidated, first-pass)

Three buildable units: **(A) voice-coil brush head**, **(B) its driver**, **(C) the
planar-plate CoreXY frame**. The brush head + driver are testable on the existing
Shapeoko HDZ before the frame exists. Quantities/specs are first-pass — verify
against datasheets before ordering.

## A. Voice-coil brush head
| Item | Spec | Qty | Notes |
|---|---|---|---|
| Pole | 1018 steel, Ø16×28 + register | 1 | lathe (`pole.py`) |
| Cup | 1018 steel, Ø32×46, opens down | 1 | lathe (`steel_cup.py`) |
| Magnet | NdFeB N52 disc Ø16×10, axial | 1 | K&J-class |
| Magnet wire | AWG26 enamel | ~10 m | ~160 turns, k_f≈3.3–4.2 N/A |
| Flexure blades | spring steel shim, t=0.1, ~122×20 | 2 | etch/laser/waterjet (`blade.py`) |
| Bobbin | printed flangeless former | 1 | `bobbin.py` |
| Carrier | printed | 1 | `carrier.py` |
| Brush holder | printed, 8 mm ferrule | 1 | `brush_holder.py` |
| Clamp plates | printed | 4 | `clamp_plate.py` (2 carrier + 2 ground)* |
| Body collar | printed, Ø65 HDZ mount | 1 | `body_collar.py` |
| Flexure ground | printed U-frame | 1 | `flexure_ground.py` |
| Brush | round, 8 mm ferrule | — | the tool |
| Fasteners | M3 (attach/clamp), M5 (collar↔ground) | — | + 3× long M3 stack |
| Epoxy | for magnet/pole bond + coil-to-former | — | |
\* ground needs 4 clamp plates (2 per blade end); add 2 more if clamping both ends.

## B. Voice-coil driver
| Item | Spec | Notes |
|---|---|---|
| H-bridge | DRV8874 (or DRV8412 / DRV8701+MOSFETs) | 24 V, ~6 A peak |
| Current sense | INA240A2 + 10 mΩ ≥1 W shunt | bidirectional |
| MCU | STM32G474 (or Teensy 4.0) | 20 kHz current loop |
| Supply | 24 V, bulk cap ≥470 µF low-ESR | |
| Comms | CAN-FD transceiver (final) / USB (proto) | |
| Encoder (opt) | AS5311 + 2 mm-pole strip | position v2 |

## C. Planar-plate CoreXY frame (landscape 4×3 ft)
| Item | Spec | Qty | Notes |
|---|---|---|---|
| Steppers | NEMA23 high-torque ≥2.5–3 N·m, low-L, dual-shaft | 2 | open-loop initially |
| Stepper drivers | 4.5 A, 56 V (owned) | 2 | |
| Belt | GT2/GT3 15 mm **steel-core** | ~12 m | resonance-critical |
| Pulleys | 30T 2GT, motor bore | 2 | ~2000 rpm @ 2 m/s |
| Idlers | ≥20 mm toothed (steel-cord bend radius) | 8 | BL/BR + 4 gantry + 2 crossover |
| MGN12 rail | ~1370 mm (X gantry) | 1 | + blocks |
| MGN12 rail | ~1120 mm (Y uprights) | 2 | + blocks |
| Plates | laser acrylic/ply (Al keepers later) | — | `plate_*.py` DXFs |
| 8020 extrusion | 2040/4040, raked easel | — | perimeter + gantry beam |
| Counterbalance | constant-force spring(s) ~34 N | 1–2 | NEVER a counterweight |
| Control host | Teensy/STM32 streaming step/dir | 1 | low-latency teleop |
| Fasteners | M3 (MGN/idlers), M5 (8020 T-nuts) | — | |

## D. Existing / host
- **Shapeoko HDZ** — prototype host (provides XY + coarse-Z); brush head drops into
  its **65 mm router clamp** (no adapter — the `body_collar` IS the 65 mm collar).

## Still to spec
- Coarse-Z stage (full machine only — the Shapeoko/HDZ covers coarse-Z for the proto).
- Marry-to-8020 detail (T-nut positions, beam ends) + final idler-offset verification.

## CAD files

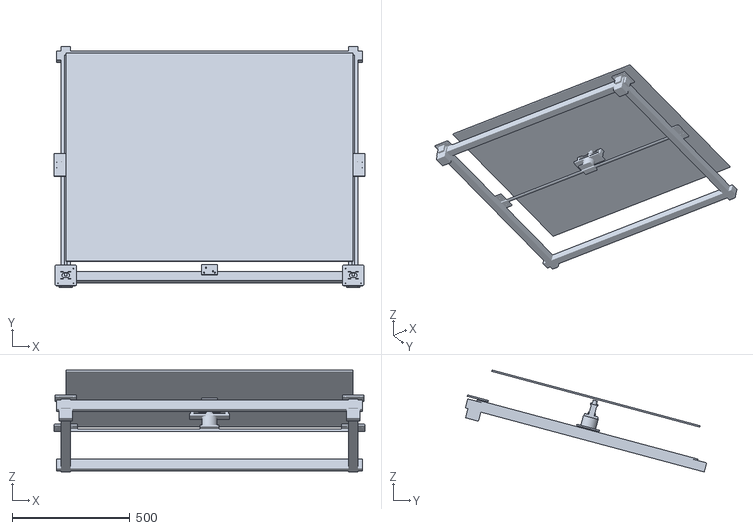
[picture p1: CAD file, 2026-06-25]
cad/build/assembly_corexy.stl
1320.0 x 1024.6 x 432.9

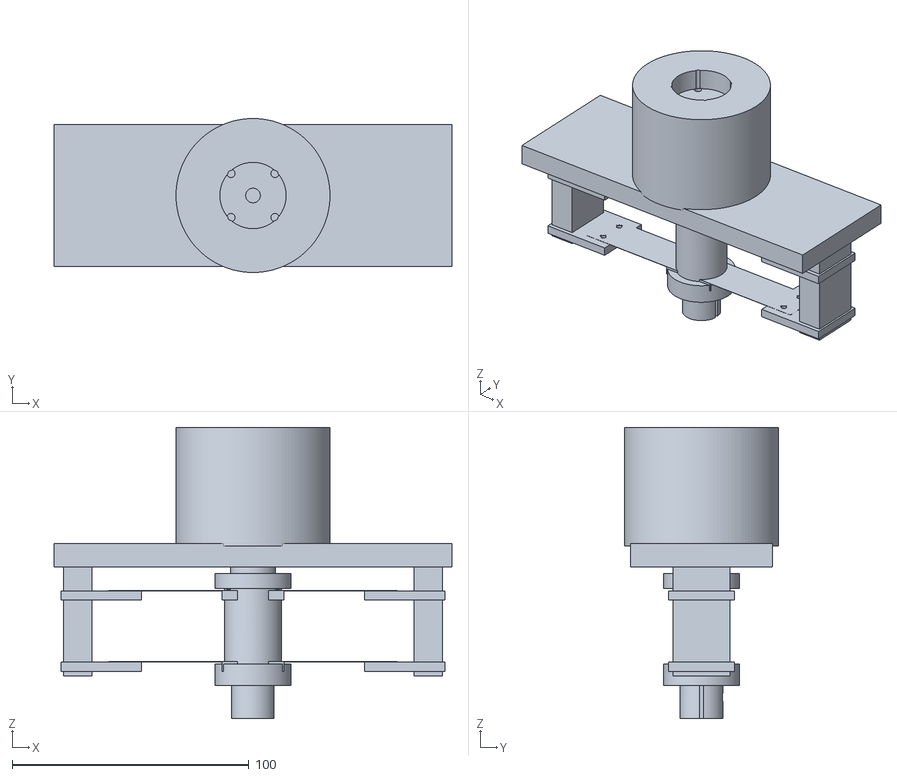
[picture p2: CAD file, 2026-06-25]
cad/build/assembly_brush.stl
168.0 x 65.0 x 123.0

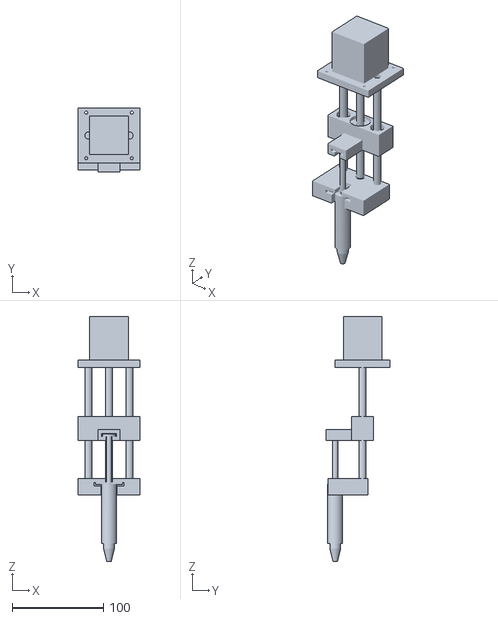
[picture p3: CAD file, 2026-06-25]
cad/build/assembly_extruder.stl
68.0 x 70.0 x 269.0

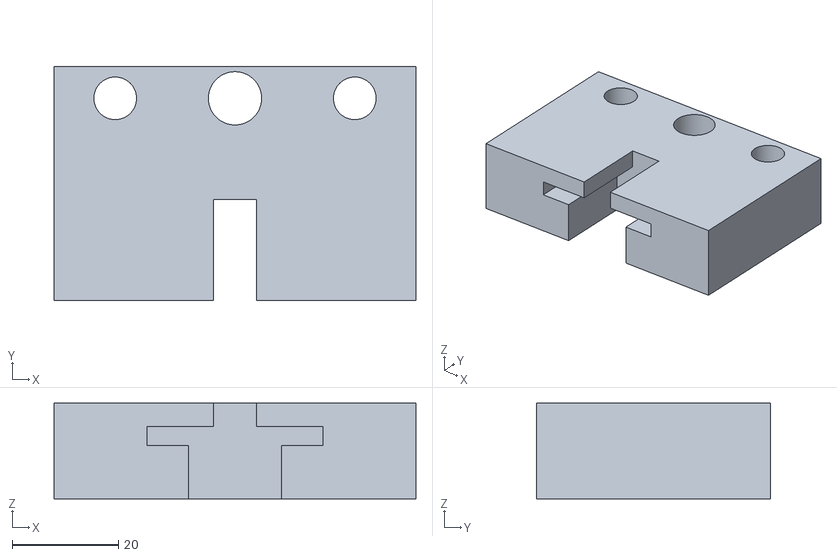
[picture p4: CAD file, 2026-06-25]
cad/build/ext_cradle.stl
68.0 x 44.0 x 18.0

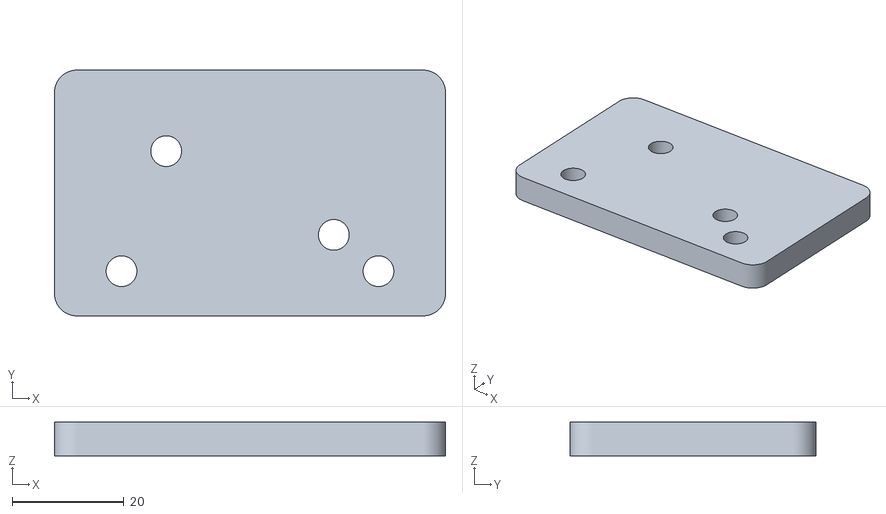
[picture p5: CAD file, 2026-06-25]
cad/build/plate_crossover.stl
70.0 x 44.0 x 6.00

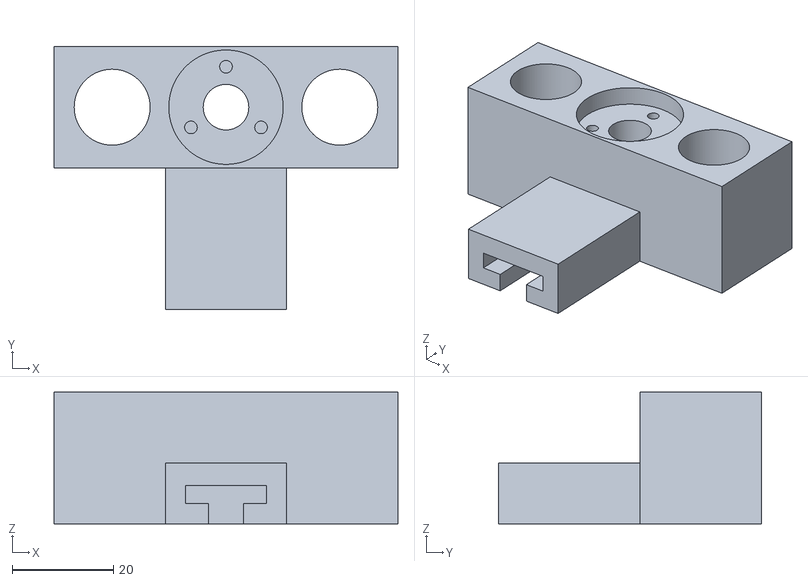
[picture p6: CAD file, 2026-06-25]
cad/build/ext_carriage.stl
68.0 x 52.0 x 26.0

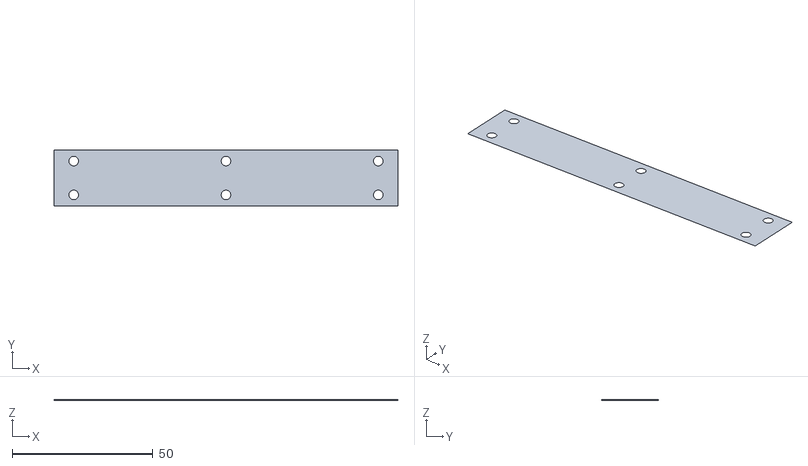
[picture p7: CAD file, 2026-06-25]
cad/build/blade.stl
122.0 x 20.0 x 0.1

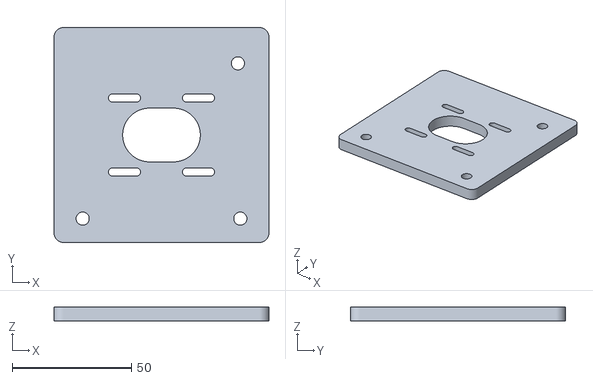
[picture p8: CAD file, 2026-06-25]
cad/build/plate_motor_corner.stl
90.0 x 90.0 x 6.00

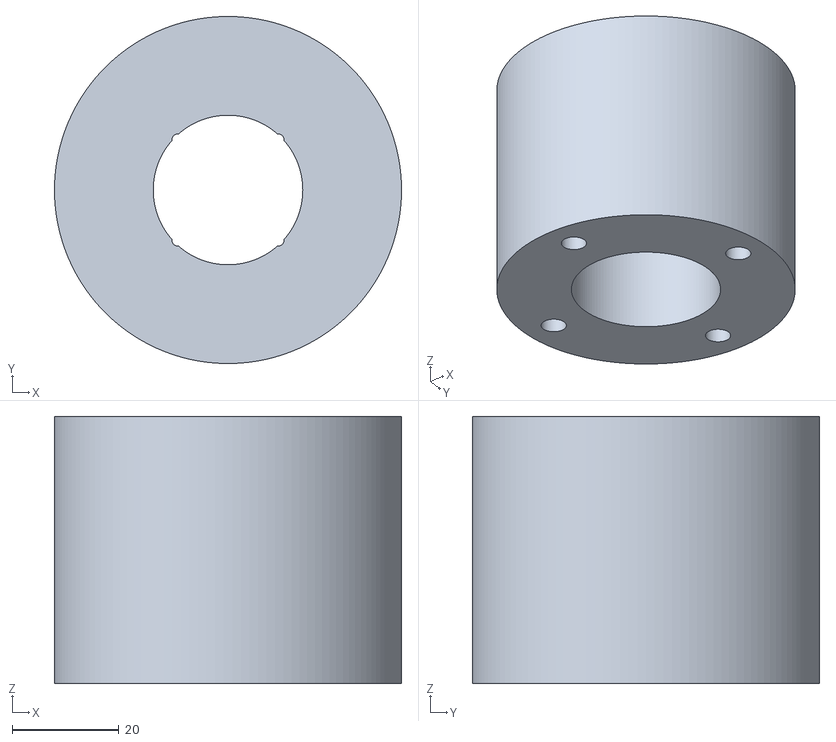
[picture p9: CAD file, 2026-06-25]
cad/build/body_collar.stl
65.0 x 65.0 x 50.0

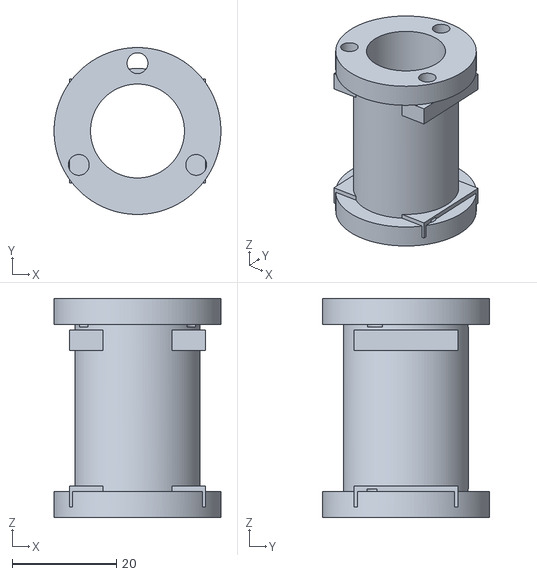
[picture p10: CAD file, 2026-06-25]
cad/build/carrier.stl
32.0 x 32.0 x 42.0

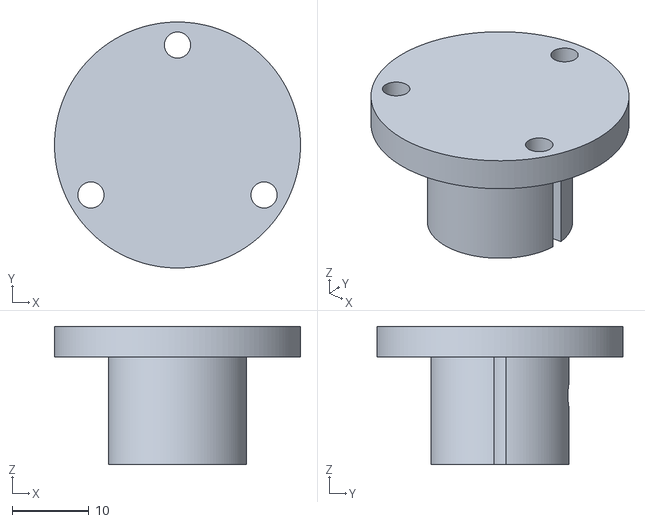
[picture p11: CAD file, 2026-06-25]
cad/build/brush_holder.stl
32.0 x 32.0 x 18.0

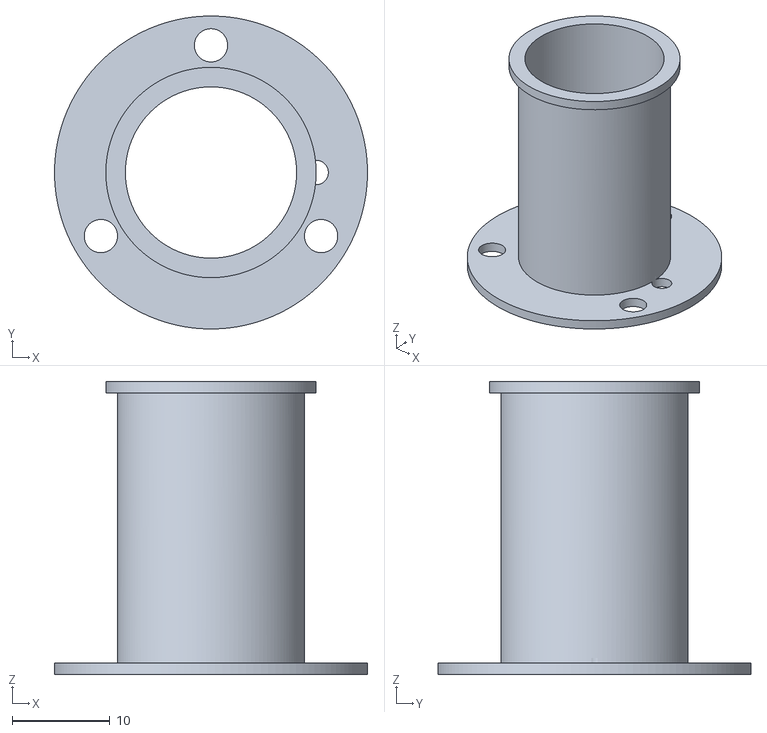
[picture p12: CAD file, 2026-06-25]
cad/build/bobbin.stl
32.0 x 32.0 x 30.0

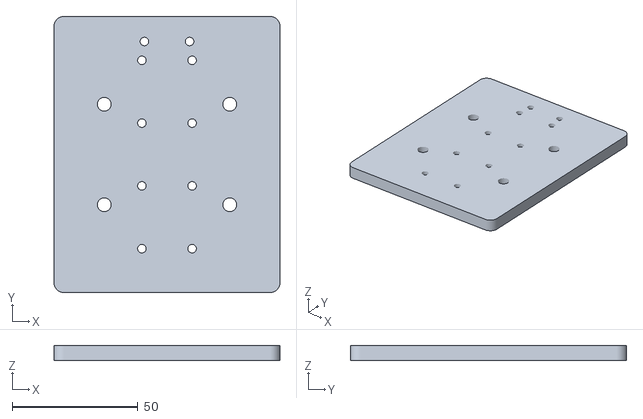
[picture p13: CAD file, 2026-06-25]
cad/build/z_carriage.stl
90.0 x 110.0 x 6.00

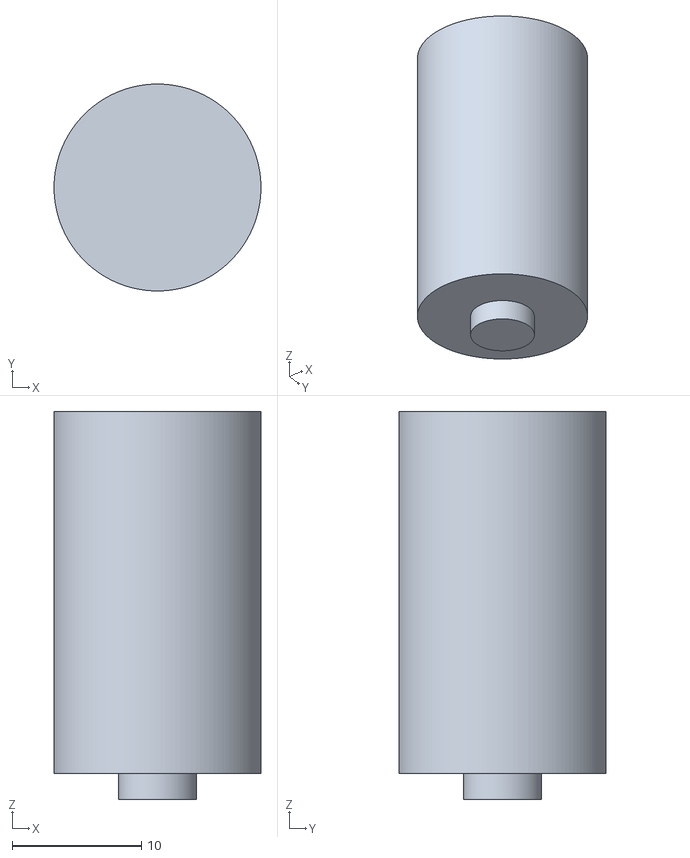
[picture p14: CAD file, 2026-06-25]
cad/build/pole.stl
16.0 x 16.0 x 30.0

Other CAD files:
cad/build/flexure_ground.stl
cad/build/plate_xcarriage.stl
cad/build/clamp_plate.stl
cad/build/steel_cup.stl
cad/build/ext_nozzle.stl
cad/build/ext_top_plate.stl
cad/build/plate_crossover.dxf
cad/build/plate_gantry_end.dxf
cad/build/plate_gantry_end.stl
cad/build/plate_motor_corner.dxf
cad/build/plate_xcarriage.dxf
cad/build/z_carriage.dxf

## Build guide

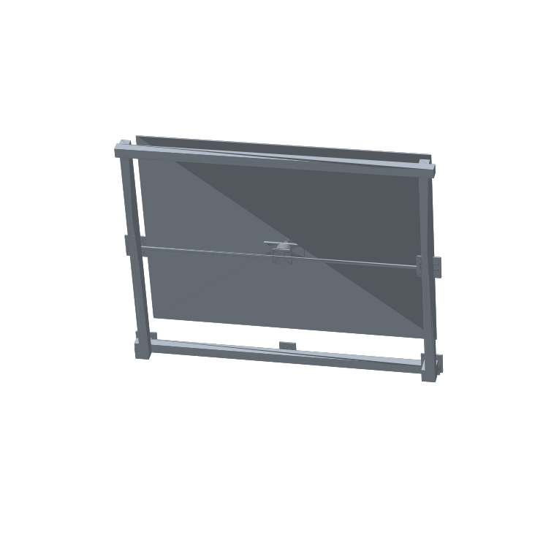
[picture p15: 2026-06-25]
cad/build/assembly_corexy.png

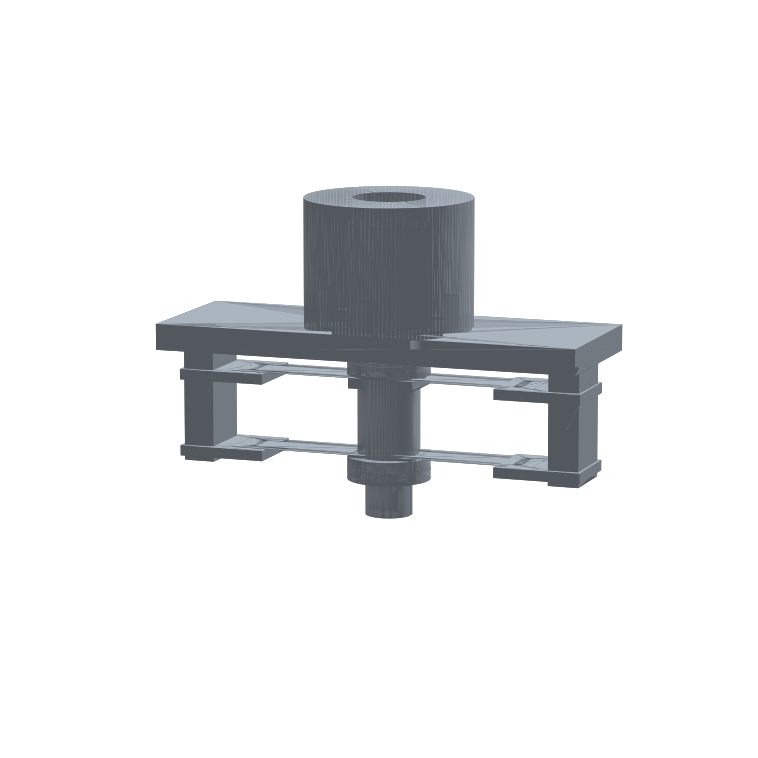
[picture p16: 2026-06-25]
cad/build/assembly_brush.png

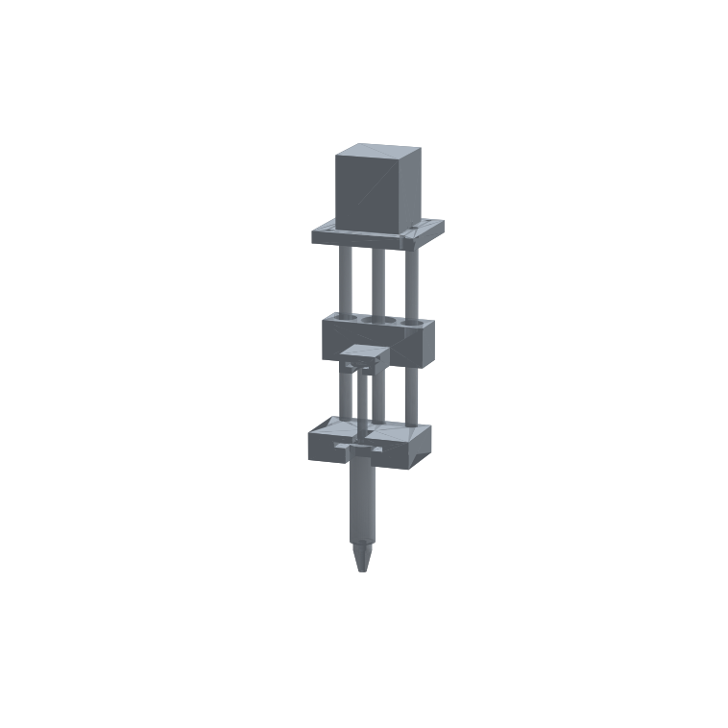
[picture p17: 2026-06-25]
cad/build/assembly_extruder.png

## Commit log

2026-06-24 Initial commit: paintbot hardware design + CAD
    Design docs (architecture, motion sizing, belt resonance, voice-coil actuator,
    brush head, extrusion head) and parametric build123d parts for the voice-coil
    brush head and gel extruder. All brush-head parts verified watertight.
2026-06-24 Brush-head z-stack fixes + planar-plate CoreXY (landscape) + frame plates
    Voice-coil head:
    - Flexure carrier/blade/clamp_plate parts (k≈0.41 N/mm validated, ~37 g mover)
    - Z-stack fix: pole 18→28 mm, cup depth 30→40, carrier bore Ø18, attach @26 BC
    - All brush-head parts watertight
    Planar-plate CoreXY (hybrid with 8020), after corexy.com R1:
    - docs/planar-corexy.md: borrow plate-locates-geometry; MGN12 + steel-core belt
    - Landscape 4 ft (X) × 3 ft (Y), motors at bottom corners
    - params_frame.py + X-carriage and gantry-end plates (DXF for laser + STL check)
2026-06-24 Planar CoreXY routing layout + motor-corner plate (landscape)
    - routing.py: reconstructed single-plane CoreXY belt topology (motors bottom,
    8 idlers, top edge free), emits build/routing.svg diagram + pulley coords
    - plate_motor_corner.py: NEMA17 on tension slots + bottom-corner idler + 8020 mount
    - Confirmed: no top-corner idler plates (top edge belt-free for counterbalance)
    - docs/planar-corexy.md: routing + plate-set status
2026-06-25 Bobbin tube extension (flangeless former) + crossover idler bracket
    - bobbin.py reworked: 30 mm flangeless former, coil epoxies on upper 16 mm near the
    cup mouth, Ø32 foot below the mouth bolts to carrier; dropped winding flanges
    (would foul the Ø22.5 cup bore — real voice coils are flangeless)
    - plate_crossover.py: 2 crossover idlers (Z-staggered via spacers) + 8020 mount
    - docs updated; all 11 CAD parts build watertight
2026-06-25 Voice-coil driver + control-loop design
    docs/voice-coil-driver.md: single-phase current-mode (=force-mode) driver.
    - DRV8874-class H-bridge, 24V, MCU-closed current loop (IN1/IN2 PWM)
    - INA240 bidirectional current sense, synchronous sampling
    - STM32G4/Teensy4, nested PI current loop + force-model feedforward
    (gravity term is a parameter: ShopBot brush-down vs vertical easel)
    - Calibration procedure, protection/watchdog, host link (USB proto / CAN-FD final)
2026-06-25 Brush-head main_body (Shapeoko HDZ 65mm mount) + assembly verify + BOM
    - body_collar.py: Ø65 HDZ router-clamp collar + steel-cup holder (drop-in mount)
    - flexure_ground.py: U-frame holding blade ends, bridges to collar; built via
    trimesh manifold booleans (OCC left coincident-face partition walls -> 9 shells);
    rails moved outboard so blade-clamp pad faces are exposed, taps made through
    - assembly_brush.py: rebuilt with REAL parts + true z-stack; renders, clearances OK
    (0.7mm coil/bore gap, foot below mouth, coil stays in gap over +/-5mm)
    - docs/bom.md: consolidated BOM (head + driver + planar frame)
    - restore IFACE_* params (extruder head still imports them); add MOUNT_* for HDZ
    - all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
2026-06-25 Coarse-Z stage: design + carriage plate
    docs/coarse-z.md: belt-driven coarse-Z for the full machine. Z is HORIZONTAL in the
    vertical easel -> gravity perpendicular to travel -> no self-lock, belt drive fine,
    head weight is a cantilever moment. MGN12 rail + 2 blocks; light NEMA17 pancake;
    carriage presents a 65mm clamp (bought) so the head collar mounts same as on the HDZ.
    - cad/z_carriage.py: laser plate (2x MGN12 + 65mm-clamp mount + belt clamp), DXF+STL
2026-06-25 Add planar CoreXY 3D assembly + commit generated CAD artifacts
    - cad/assembly_corexy.py: real flat plates placed at routing positions (landscape)
    with MGN12 rail + 8020 frame stand-ins; renders the planar frame in 3D
    - Track generated STL/DXF/SVG/PNG in cad/build (were gitignored) so the printables,
    laser DXFs, and renders are visible on GitHub; regenerate with python3 cad/<part>.py
    [assembly_brush.stl, assembly_corexy.stl, assembly_extruder.stl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]
2026-06-25 Fold machine.py massing into the plate assembly; retire machine.py
    - assembly_corexy.py is now the full raked easel: real flat plates at routing
    positions + the REAL brush head on the carriage reaching the canvas, plus 8020
    frame / MGN12 rails / NEMA23 motors / canvas slab stand-ins, raked back 15°
    - remove machine.py (+ its STL/PNG); render.py now previews assembly_corexy
    - docs updated
    [assembly_corexy.stl, machine.stl]
